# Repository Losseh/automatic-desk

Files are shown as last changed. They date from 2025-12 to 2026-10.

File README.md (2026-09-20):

# README

## Used components

### Microcontroller
Arduino Nano 328 SKU DFR0010 (from DFRobot)
[wiki](https://wiki.dfrobot.com/Arduino_Nano_328__SKU__DFR0010_)

### Current sensor
ACS712 5A

### Motor driver
[Cytron MD13S](https://www.cytron.io/p-13amp-6v-30v-dc-motor-driver)

### Motor
JGB37-555

# Troubleshooting

## Arduino-ide

### sandbox issue

```
[18644:1223/101056.126347:FATAL:setuid_sandbox_host.cc(158)] The SUID sandbox helper binary was found, but is not configured correctly. Rather than run without sandboxing I'm aborting now. You need to make sure that /home/justyna-halicz-szymanska/Programy/arduino-ide_2.3.7_Linux_64bit/chrome-sandbox is owned by root and has mode 4755.
Pułapka debuggera/breakpoint (zrzut pamięci)
```

solution
```
sudo chown root chrome-sandbox
sudo chmod g+x,u+s chrome-sandbox
```

### Error: programmer is not responding

trying to upload a program to dfrduino nano 4.0 using android ide. but getting:
```
Sketch uses 924 bytes (3%) of program storage space. Maximum is 30720 bytes.
Global variables use 9 bytes (0%) of dynamic memory, leaving 2039 bytes for local variables. Maximum is 2048 bytes.
Error: programmer is not responding Warning: attempt 1 of 10: not in sync: resp=0x00
Error: programmer is not responding Warning: attempt 2 of 10: not in sync: resp=0x00
Error: programmer is not responding Warning: attempt 3 of 10: not in sync: resp=0x00
...
```

solution
```
Select Arduino Nano
Try ATmega328P
If that doesn't work, try ATmega328P (Old Bootloader)

The Nano 4.0 is based on the ATmega328P, and the bootloader variant matters.
```

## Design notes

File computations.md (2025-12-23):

* prędkość blatu / obroty
Dv = 5.5 mm/rot

* pożądana prędkość blatu

Vb = 25 - 36 mm/s

* zależność prędkości blatu / obroty z obrotami silnika (Ev)

Vb [mm/s] = Dv [mm/rot] * Ev [rot/s]

* wyliczenie Ev
Ev = Vb / Dv

1. 25 mm/s
Ev1 = 25 mm/s / 5.5 mm/rot ~= 5Hz = 300rpm
Ev2 = 35 mm/s / 5.5 mm/rot ~= 7Hz = 420rpm

powiedzmy że trzeba przemieścić 500mm
Dv = L / R
L = 500mm
R = liczba obrotów = L / Dv = 500 / 5.5 ~= 100
R = Ev * t
Dv = L / Ev / t
Ev = L / Dv / t
Ev = 500 / 5.5 / 60 (*60) = 90RPM

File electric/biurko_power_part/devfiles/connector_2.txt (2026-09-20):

(Device File generated by Lepton EDA netlister Allegro backend)
PACKAGE #f
CLASS IO
PINCOUNT 2
END

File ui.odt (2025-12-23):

# INPUTY (co fizycznie podłączasz)

## 1️⃣ UP — przycisk monostabilny (tact switch)

Funkcje:

- krótkie wciśnięcie / trzymanie → jazda w górę manualna
- długie przytrzymanie (> ~500 ms) → start auto jazdy do MAX
- puszczenie (manual) → STOP
- dowolne wciśnięcie w trakcie auto → STOP

Sprzęt:

- NO
- INPUT_PULLUP
- aktywny LOW

## 2️⃣ DOWN — przycisk monostabilny

Funkcje:

- krótkie / trzymanie → jazda w dół manualna
- długie przytrzymanie (> ~500 ms) → start auto jazdy do MIN
- puszczenie (manual) → STOP
- dowolne wciśnięcie w trakcie auto → STOP

Sprzęt:

- NO
- INPUT_PULLUP
- aktywny LOW

## 3️⃣ CAL / SET — przycisk serwisowy

Funkcje:

- przytrzymanie ~5 s → kalibracja (jazda w dół do krańcówki, zerowanie)
- krótkie wciśnięcie → brak akcji (normalny tryb)

Sprzęt:

- NO
- INPUT_PULLUP
- aktywny LOW
- najlepiej schowany (nie do codziennego użytku)

## 4️⃣ LIMIT_DOWN — krańcówka dolna

Funkcje:

- wykrycie minimum
- twardy STOP
- punkt referencyjny do kalibracji

Sprzęt:

- NO (NC jeśli chcesz + bezpieczeństwo)
- INPUT_PULLUP
- aktywny LOW
- bez debounce albo 1–2 ms max

## 5️⃣ (opcjonalnie) LIMIT_UP — krańcówka górna

Funkcje:

- zabezpieczenie mechaniczne
- twardy STOP przy błędzie softu

Sprzęt:

- NO
- INPUT_PULLUP
- aktywny LOW

# OUTPUTY (co sygnalizujesz)

## 🔴 ERROR — czerwona LED

Świeci ciągle:

- błąd krańcówki
- przeciążenie / kolizja
- rozjazd nóg
- brak kalibracji

Miga:

- kody błędów (opcjonalnie)

## 🟢 STATUS / READY — zielona LED

Zachowanie:

- świeci ciągle → gotowe
- miga wolno → auto jazda
- miga szybko → kalibracja

## ⚙️ (opcjonalnie) DEBUG / SYNC — LED

- synchronizacja nóg
- tryb serwisowy
- do testów

# Zasady globalne (najważniejsze)

- INPUT_PULLUP + aktywne LOW – wszędzie
- dowolne naciśnięcie przycisku podczas ruchu = STOP
- krańcówki i błędy mają wyższy priorytet niż UI
- brak przełączników trybu (manual/auto)
- UI sterowane czasem przytrzymania

# TL;DR – minimalna wersja

Wystarczy:

- 2× przycisk (UP, DOWN)
- 1× CAL (ukryty)
- 1× krańcówka dolna
- 2× LED (STATUS, ERROR)

To jest pełne, bezpieczne i ergonomiczne UI dla biurka regulowanego.

Jeśli chcesz, następny krok:

- rozpisać pinout MCU pod te sygnały,
- albo pełną maszynę stanów (IDLE / MANUAL / AUTO / CAL / FAULT),
- albo checklistę edge-case’ów, które warto przetestować przed pierwszym uruchomieniem.

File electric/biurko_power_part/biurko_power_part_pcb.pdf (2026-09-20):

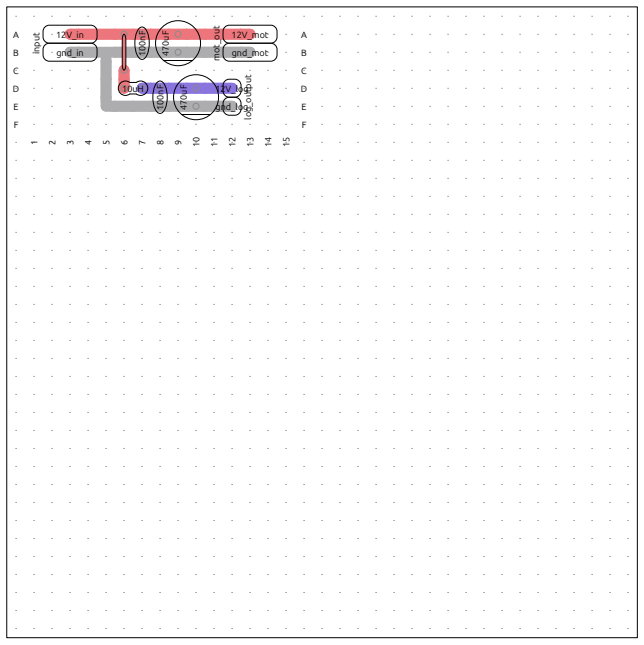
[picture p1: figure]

12V_log gnd_log 12V_mot gnd_mot 12V_in gnd_in | 10uH | 470uF 470uF | log_output mot_out input | 100nF | 100nF 1 | 2 | 3 | 4 | 5 | 6 | 7 | 8 | 9 | 10 | 11 | 12 | 13 | 14 | 15 ABCDEF | ABCDEF

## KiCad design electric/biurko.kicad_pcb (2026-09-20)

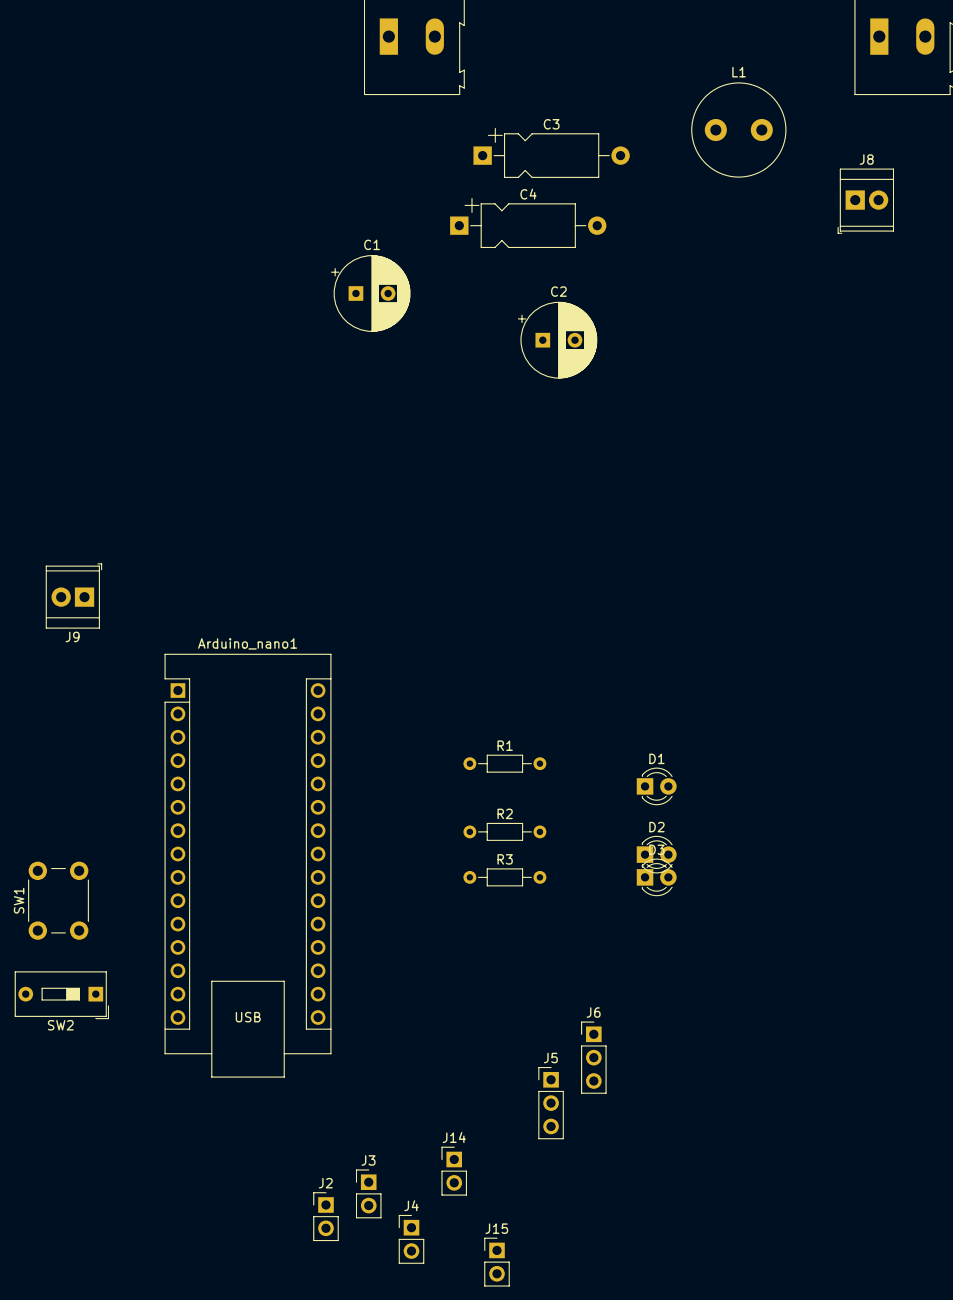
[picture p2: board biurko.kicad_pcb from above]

Board: 2 copper layers, 25 parts (0 on the bottom side), 21 nets, no tracks yet.

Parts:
Arduino_nano1: Arduino_Nano
C1, C2: 470uF; CP_Radial_D8.0mm_P3.50mm
C3, C4: 100nF; CP_Axial_L10.0mm_D4.5mm_P15.00mm_Horizontal
D1: green; LED_D3.0mm
D2: red; LED_D3.0mm
D3: yellow; LED_D3.0mm
J1: 12V input screw terminal; TerminalBlock_Altech_AK300-2_P5.00mm
J2, J15: upper limit; PinHeader_1x02_P2.54mm_Vertical
J3, J14: lower limit; PinHeader_1x02_P2.54mm_Vertical
J4: encoder; PinHeader_1x02_P2.54mm_Vertical
J5: outer control; PinHeader_1x03_P2.54mm_Vertical
J6: motor control; PinHeader_1x03_P2.54mm_Vertical
J7: 12V motors screw terminal; TerminalBlock_Altech_AK300-2_P5.00mm
J8: 12V logic screw terminal; TerminalBlock_TE_282834-2_1x02_P2.54mm_Horizontal
J9: power input; TerminalBlock_TE_282834-2_1x02_P2.54mm_Horizontal
L1: 10uH; L_Radial_D10.0mm_P5.00mm_Neosid_SD12_style3
R1, R2, R3: 220R; R_Axial_DIN0204_L3.6mm_D1.6mm_P7.62mm_Horizontal
SW1: callibrate; SW_PUSH_6mm
SW2: debug; SW_DIP_SPSTx01_Slide_9.78x4.72mm_W7.62mm_P2.54mm

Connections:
+5VL: Arduino_nano1.4 (5V), R1.1, R2.1, R3.1
+7.5V: Arduino_nano1.1 (VIN), J9.1
+12L: C2.1, C4.1, J8.2, L1.2
+12P: C1.1, C3.1, J1.2, J7.2, L1.1
/callibrate_trg: Arduino_nano1.11 (D8), SW1.2
/callibrated: Arduino_nano1.10 (D7), D1.1 (K)
/debug: Arduino_nano1.15 (D13/SCK), SW2.1 (A)
/down: Arduino_nano1.7 (D4), J5.2
/encoder_out: Arduino_nano1.5 (D2/INT0), J4.1
/error: Arduino_nano1.9 (D6), D2.1 (K)
/lower_lmt: Arduino_nano1.13 (D10), J3.1, J15.1
/pwm: Arduino_nano1.14 (D11/MOSI), J6.2
/status: Arduino_nano1.8 (D5), D3.1 (K)
/up: Arduino_nano1.6 (D3/INT1), J5.1
/upper_lmt: Arduino_nano1.12 (D9), J2.1, J14.1
GND: Arduino_nano1.2 (GND), J2.2, J3.2, J4.2, J5.3, J6.3, J9.2, J14.2, J15.2, SW1.1, SW2.2 (B)
GND1: C1.2, C3.2, J7.1
unnamed: D1.2 (A), R1.2
unnamed: D2.2 (A), R2.2
unnamed: D3.2 (A), R3.2
unnamed: C2.2, C4.2, J8.1

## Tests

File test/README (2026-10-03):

This directory is intended for PlatformIO Test Runner and project tests.

Unit Testing is a software testing method by which individual units of
source code, sets of one or more MCU program modules together with associated
control data, usage procedures, and operating procedures, are tested to
determine whether they are fit for use. Unit testing finds problems early
in the development cycle.

More information about PlatformIO Unit Testing:
- https://docs.platformio.org/en/latest/advanced/unit-testing/index.html

Run tests with:
pio test -e native -vvv

Install PlatformIO with:
pipx install platformio

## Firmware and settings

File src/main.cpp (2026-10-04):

#include "button.h"
#include "led.h"
#include "motor.h"
#include "current_sensor.h"
#include "limit_switch.h"
#include "components.h"
#include "position.h"
#include "state/command_controller.h"
#include "Arduino.h"

// leds
Led yellowLed(6);
Led redLed(7);
Led builtInLed(LED_BUILTIN);

// buttons
Button upBtn(3);
Button downBtn(4);
Button calBtn(9);

// limit switch
LimitSwitch lowerLimitSwitch(10);

// current sensor
// TODO aszymanski: 600 as the max value is arbitrary. we need to measure first what current
// does the motor consume in case of a short-circuit mode work and adjust the value accordingly
// normal work up = ~44
// normal work down = ~29
// blocked = ~304
CurrentSensor currentSensor(A0, {527, 200, 3, 5});

// motor
MotorPins motorPins = {11, 12};
MotorConstants motorConstants = {10};
Motor motor(motorPins, motorConstants);

// encoder
const int encoderPin = 2;
constexpr unsigned long MIN_PULSE_INTERVAL_US = 1000;

volatile unsigned long lastPulse = 0;
volatile long encoderPulses = 0;

Position position;

void onEncoderPulse() {
    unsigned long now = micros();

    if (now - lastPulse >= MIN_PULSE_INTERVAL_US) {
        encoderPulses++;
        lastPulse = now;
    }
}

// command state controller
Components components = {
  upBtn,
  downBtn,
  motor,
  lowerLimitSwitch,
  currentSensor
};
CommandController controller(components);

// loop counter
uint8_t loopCounter = 0;

// response
String response;

// the setup function runs once when you press reset or power the board
void setup() {

  // initialize motor
  motor.begin();

  // initialize LEDs
  yellowLed.begin();
  redLed.begin();
  builtInLed.begin();

  // initialize buttons
  upBtn.begin();
  downBtn.begin();
  calBtn.begin();

  // initialize limit switch
  lowerLimitSwitch.begin();

  // initialize encoder interrupt
  pinMode(encoderPin, INPUT_PULLUP);
  attachInterrupt(
    digitalPinToInterrupt(encoderPin),
    onEncoderPulse,
    RISING
  );

  Serial.begin(9600);
}

void updateButtons() {
  upBtn.update();
  downBtn.update();
  calBtn.update();
}

void updatePosition() {
  noInterrupts();
  long pulses = encoderPulses;
  encoderPulses = 0;
  interrupts();

  if (pulses > 0) {
      position.update(pulses, motor.getDirection());
  }
}

// the loop function runs over and over again forever
void loop() {

  bool lowerLimitActive = lowerLimitSwitch.isPressed();

  if (motor.getDirection() == Direction::DOWN && lowerLimitActive) {
    motor.stopInstant();
  }

  updateButtons();

  controller.update();

  // TODO aszymanski: what information should those diodes present?
  // redLed.set(!downBtn.isPressed());
  // yellowLed.set(!upBtn.isPressed());

  currentSensor.measure();
  motor.update();
  updatePosition();

  // if (Serial.available() && loopCounter == 0) {
  //   int inByte = Serial.read();

  //   if (inByte == '0') {
  //     motor.setSpeed(0);
  //   } else if (inByte == '1') {
  //     motor.setSpeed(50);
  //   } else if (inByte == '2') {
  //     motor.setSpeed(150);
  //   } else if (inByte == '3') {
  //     motor.setSpeed(255);
  //   } else if (inByte == '4') {
  //     motor.setSpeed(-50);
  //   } else if (inByte == '5') {
  //     motor.setSpeed(-150);
  //   } else if (inByte == '6') {
  //     motor.setSpeed(-255);
  //   }

  //   // yellow led
  //   if (inByte == 'a') {
  //     yellowLed.switchOn();
  //   } else if (inByte == 'z') {
  //     yellowLed.switchOff();
  //   }

  //   // red pin
  //   if (inByte == 's') {
  //     redLed.switchOn();
  //   } else if (inByte == 'x') {
  //     redLed.switchOff();
  //   }

  // }

  // if (loopCounter == 255) {
  //   loopCounter = 0;
  //   Serial.print("position = ");
  //   Serial.print(position.getPosition());
  //   Serial.print("\n");

  // Serial.print("crnt raw=");
  // Serial.print(currentSensor.previous());
  // Serial.print(" ma=");
  // Serial.print(currentSensor.movingAverage());
  // Serial.print("\n");
  // } else {
  //   loopCounter++;
  // }

}

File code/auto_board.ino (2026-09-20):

/*
  Blink

  Turns an LED on for one second, then off for one second, repeatedly.

  Most Arduinos have an on-board LED you can control. On the UNO, MEGA and ZERO
  it is attached to digital pin 13, on MKR1000 on pin 6. LED_BUILTIN is set to
  the correct LED pin independent of which board is used.
  If you want to know what pin the on-board LED is connected to on your Arduino
  model, check the Technical Specs of your board at:
  https://docs.arduino.cc/hardware/

  modified 8 May 2014
  by Scott Fitzgerald
  modified 2 Sep 2016
  by Arturo Guadalupi
  modified 8 Sep 2016
  by Colby Newman

  This example code is in the public domain.

  https://docs.arduino.cc/built-in-examples/basics/Blink/
*/

// the setup function runs once when you press reset or power the board
void setup() {
  // initialize digital pin LED_BUILTIN as an output.
  pinMode(LED_BUILTIN, OUTPUT);

  Serial.begin(9600);
}

// the loop function runs over and over again forever
void loop() {
  // digitalWrite(LED_BUILTIN, HIGH);  // turn the LED on (HIGH is the voltage level)
  // delay(1000);                      // wait for a second
  // digitalWrite(LED_BUILTIN, LOW);   // turn the LED off by making the voltage LOW
  // delay(1000);                      // wait for a second

  String response;
  String on = String("on");
  String off = String("off");

  if (Serial.available()) {
    int inByte = Serial.read();

    uint8_t ledState = (inByte == '0') ? LOW : HIGH;
    digitalWrite(LED_BUILTIN, ledState);

    if (ledState) {
      Serial.println(on);
    } else {
      Serial.println(off);
    }

    Serial.write(ledState);

    delay(100);
  }
}

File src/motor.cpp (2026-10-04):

#include "motor.h"
#include "Arduino.h"

#define MAX_PWM 255

Motor::Motor(MotorPins pins, MotorConstants constants): pins(pins), constants(constants), state({0, 0}) {}

void Motor::begin() {
  pinMode(pins.pwm, OUTPUT);
  pinMode(pins.dir, OUTPUT);
  stopInstant();
}

void Motor::update() {
  int diff = state.target - state.actual;

  if (abs(diff) < constants.maxChange) {
    state.actual = state.target;
  } else if (diff > 0) {
    state.actual += constants.maxChange;
  } else if (diff < 0) {
    state.actual -= constants.maxChange;
  }

  state.actual = constrain(state.actual, -MAX_PWM, MAX_PWM);

  if (diff != 0) {
    Serial.write("motor exp=");
    Serial.print(state.target);
    Serial.write(" act=");
    Serial.print(state.actual);
    Serial.write("\n");
  }

  apply();
}

void Motor::setSpeed(int speed) {
  state.target = constrain(speed, -MAX_PWM, MAX_PWM);
}

void Motor::up() {
  setSpeed(MAX_PWM);
}

void Motor::down() {
  setSpeed(-MAX_PWM);
}

void Motor::stop() {
  setSpeed(0);
}

void Motor::stopInstant() {
  state.actual = 0;
  state.target = 0;
  apply();

  Serial.write("motor stopped inst\n");
}

int Motor::speed() const {
  return state.actual;
}

Direction Motor::getDirection() const {
  return state.actual < 0 ? Direction::DOWN : Direction::UP;
}

void Motor::apply() {
  int pwm = abs(state.actual);
  uint8_t dir = state.actual >= 0 ? HIGH : LOW;

  digitalWrite(pins.dir, dir);
  analogWrite(pins.pwm, pwm);
}

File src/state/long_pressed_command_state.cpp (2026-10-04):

#include "command_state.h"
#include "long_pressed_command_state.h"
#include "Arduino.h"

LongPressedCommandState::LongPressedCommandState(CommandStatePool& commandStatePool, Components& components) : 
  commandStatePool(commandStatePool),
  components(components)
  {}

void LongPressedCommandState::init(const StateContext& stateContext) {
  direction = stateContext.direction;
  initiatingButton = direction == Direction::UP ? 
    &components.upBtn : 
    &components.downBtn;
}

StateTransition LongPressedCommandState::update(StateContext& stateContext) {
  // button released -> end of long-press
  if (!initiatingButton->isPressed()) {
    components.motor.stop();

    Serial.write("long-pressed -> idle\n");
    return {
      commandStatePool.idle,
      {}
    };
  }

  if (components.currentSensor.exceedsLimit()) {
    components.motor.stopInstant();
    return {
      commandStatePool.idle,
      {}
    };
  }

  // TODO aszymanski: stop instant should happen also when current exceeds the limit
  switch (direction) {
    case Direction::UP:
      components.motor.up();
      break;

    case Direction::DOWN:
      if (components.lowerLimitSwitch.isPressed()) {
        components.motor.stopInstant();
      } else {
        components.motor.down();
      }
      break;
  }


  return {
    this,
    stateContext
  };
}

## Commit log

2026-09-20 init code + sync
    [biurko.kicad_pcb, biurko.kicad_sch, biurko_power_part.kicad_pcb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]
2026-09-24 motor control + current sensor
    - handle motor control with PWM via serial port
    - handle current sensor readings
2026-10-01 implement motor soft start / stop
2026-10-02 clean-up
    split desk_code.ino into smaller files
    introduce c++ classes and object-programming
    implement limit switch
2026-10-02 simplify + couple buttons to motor movement
    simplify code by removing pointers in favor for simple instances
    implement very simple state machine coupling buttons to motor target speed
2026-10-02 clean up
    initialize buttons state to LOW
    improve naming
2026-10-03 add wait-for-release state between short-press and idle
    this avoids a situation, that pressed state is triggered immediately after short-press exited. the reason was that the button triggering state transition might still be pressed when entering idle
    [long_pressed_command_state.cpp]
2026-10-03 clean up arduino project
    remove obsolete desk_code directory
2026-10-03 add exceedsLimit method to current sensor
2026-10-04 encoder handling + current safety fuse
    add support for encoder with time filter to skip false RISING signals
    turn off the motor immediately when overcurrent is sensed
    [long_pressed_command_state.cpp, main.cpp]
